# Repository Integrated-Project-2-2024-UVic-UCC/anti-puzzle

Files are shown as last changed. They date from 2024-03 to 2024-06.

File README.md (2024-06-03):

<div align="center">
<h1 align="center">ANTI-PUZZLE 🧩</h1>
</div>
<div align="center">

IMAGE ALT TEXT HERE (https://www.youtube.com/watch?v=cqxajy784bM)

</div>

<p><strong>Forget conventional puzzles❗</strong> Anti-Puzzle offers a unique and engaging challenge designed specifically for elderly.🤶 It goes beyond traditional puzzles, aiming to improve reflexes, decision-making skills, and hand-eye coordination, all while keeping things fun and interactive. </p>

<p><strong>How does it work❓</strong> Instead of fitting pieces together, the goal is to strategically position a piece to prevent it from escaping. This fast-paced and engaging gameplay keeps players on their toes, sharpening their mental agility and reaction time.🫳🎮 </p>

## About the project

- 🔁 Bidirectional Movement CoreXY  
- 📲 People Interaction
- 🧲 Magnetic Detection for the Repulsion
- 💪 Different Levels in function of Capabilities

<br>

## Project *review*
<div align="center">
<table>
<tr>
<td width="100%">
<h3 align="center">Anti-Puzzle BOM 📖✔️</h3>
<div align="center">
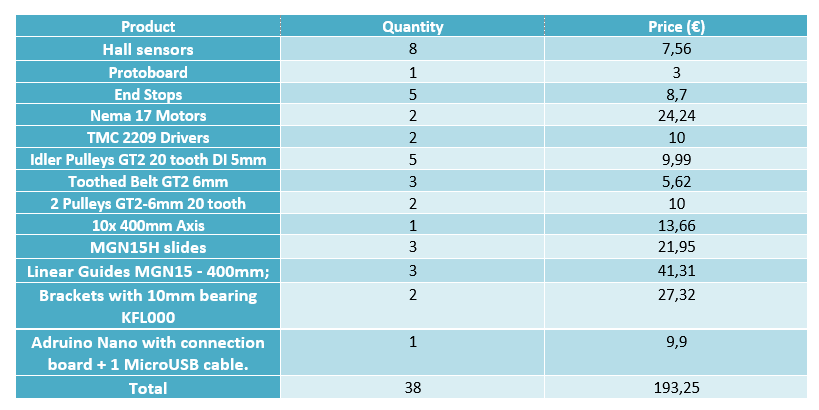
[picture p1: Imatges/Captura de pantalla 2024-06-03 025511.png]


<p>In this section you will see each of the components that will shape this project. For each component you will have a purchase link.💲 </p>
</div>
                                                                                      
</td>

<table>
<tr>
<td width="50%">
<h3 align="center">Mechanical Part ⚙️</h3>
<div align="center">
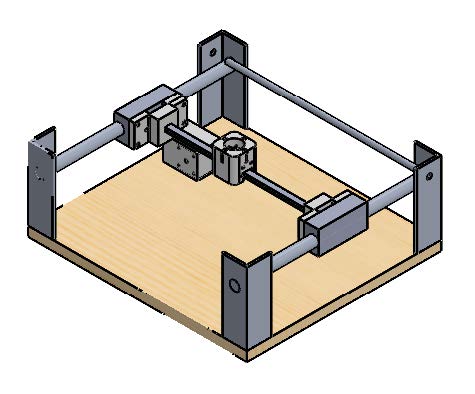
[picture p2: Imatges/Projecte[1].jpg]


<p>In this section you will be able to have blueprints and printable files as well as the original files of each one of the pieces.</p>
</div>
                                                                                      
</td>       

<td width="50%">
<h3 align="center">Electrical Part ⚡</h3>
<div align="center">
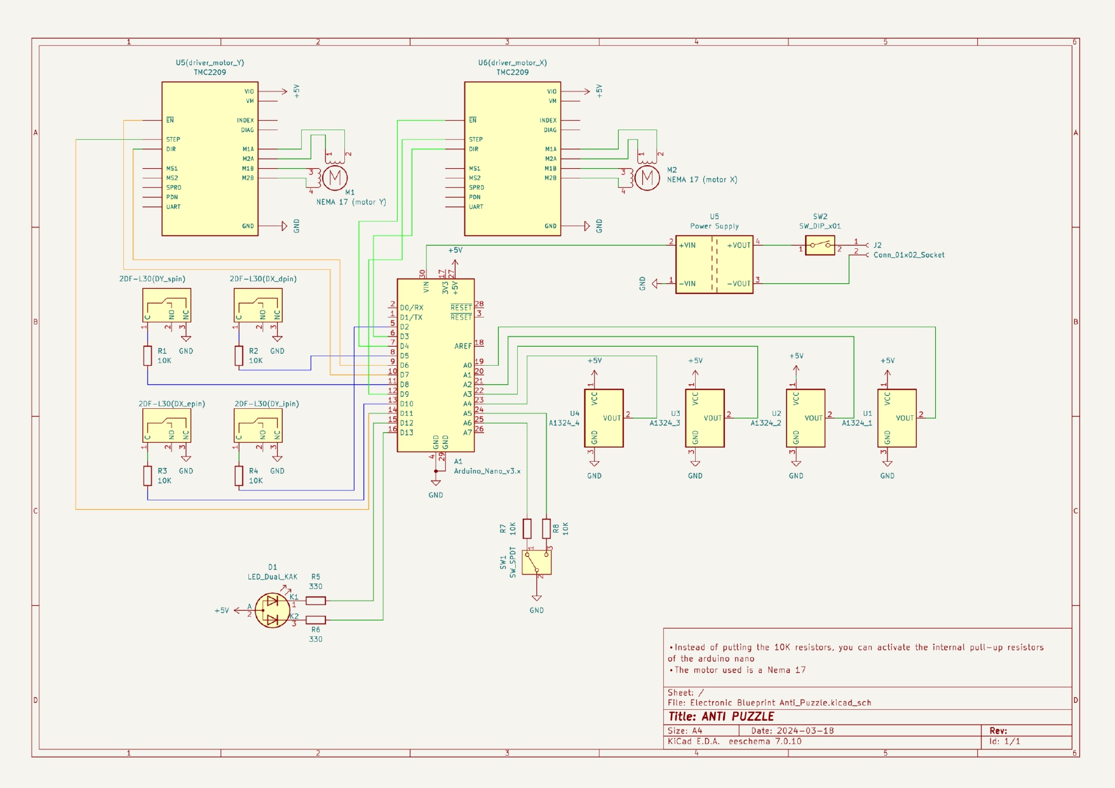
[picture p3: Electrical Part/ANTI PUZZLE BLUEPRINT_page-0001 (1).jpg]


<p>In this section you will be able to see the drawings and the electronic designs as well as the datasheets.</p>
</div>
                                                                                      
</td>  
</table>                                                                                 
</div>
<br>

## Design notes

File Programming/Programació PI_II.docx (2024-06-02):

Especificaciones del Motor NEMA 17HS8401

1. Torque: Hasta 0.4 Nm (holding torque)
2. Velocidad: Máxima de 1000-1200 RPM dependiendo del voltaje y driver
3. Corriente nominal: Aproximadamente 1.7 A por fase
4. Tamaño: Compacto, adecuado para aplicaciones de bajo espacio

Análisis de los Cálculos

En el documento proporcionado, se detallan los siguientes resultados clave:

1. Torque requerido:
  - Torque total requerido (T): 0.1746 Nm
  - Torque de aceleración (Ta): 0.00032948 Nm
  - Torque de carga (TL): 0.1160 Nm
2. Velocidad requerida:
  - Velocidad de operación (Vm1): 954.9 RPM

Comparación con las Especificaciones del Motor

1. Torque: El motor NEMA 17HS8401 proporciona un torque de hasta 0.4 Nm, lo cual es más que suficiente para cubrir el torque total requerido de 0.1746 Nm. Esto incluye el torque de carga y el de aceleración, más un factor de seguridad de 1.5.
2. Velocidad: El motor NEMA 17HS8401 puede operar a velocidades de hasta 1200 RPM, lo cual es adecuado dado que la velocidad requerida es de aproximadamente 954.9 RPM.

Justificación

- Capacidad de Torque: El motor tiene una capacidad de torque que es más del doble del requerido (0.4 Nm frente a 0.1746 Nm), lo que asegura que pueda manejar la carga sin sobrecarga y proporciona un margen de seguridad adecuado.
- Velocidad de Operación: La velocidad de operación del motor (hasta 1200 RPM) excede ligeramente la velocidad requerida de 954.9 RPM, asegurando que pueda cumplir con las necesidades de operación incluso en condiciones variables.
- Factores de Seguridad: El análisis incluye un factor de seguridad de 1.5, lo cual es considerado adecuado para la mayoría de aplicaciones industriales y asegura una operación confiable del sistema.

El motor NEMA 17HS8401 es una elección óptima para la aplicación debido a su capacidad para manejar el torque y la velocidad requeridos, así como a su tamaño compacto y eficiencia. Los cálculos muestran que el motor puede manejar la carga con un margen adecuado de seguridad, garantizando así un rendimiento confiable y eficiente.

Justificación del Uso de un Solo Imán Grande en Lugar de Múltiples Imanes Pequeños

Contexto de la Decisión

En el proyecto, se decidió utilizar un solo imán grande en lugar de múltiples imanes pequeños para cumplir con los requisitos operativos y de rendimiento. La elección se centró en asegurar una fuerza de sujeción adecuada y mantener la precisión del sistema para un rendimiento óptimo durante el uso.

Detalles del Imán Seleccionado

El imán seleccionado es un imán de samario disco Ø 25x5 mm niquelado (Referencia: SD-25-05-NI), cuyas especificaciones técnicas son:

- Material: Samario
- Forma: Disco
- Dimensiones: 25 mm de diámetro y 5 mm de alto
- Fuerza de sujeción: 4,90 kg aproximadamente
- Temperatura máxima de servicio: 300 ºC
- Remanencia: 1.03-1.08 T
- Peso: 20 g

Razones para Elegir un Solo Imán Grande

1. Fuerza de Sujeción:
  - Imanes Pequeños: Requerirían varios imanes pequeños para alcanzar la misma fuerza de sujeción que un imán grande. La distribución de fuerza podría no ser uniforme, lo que puede llevar a puntos de sujeción ineficaces y posibles fallos en el sistema.
  - Imán Grande: Proporciona una fuerza de sujeción concentrada de 4,90 kg, asegurando una sujeción más robusta y uniforme.
2. Precisión Mejorada:
  - Imanes Pequeños: La colocación de varios imanes pequeños puede llevar a desalineaciones y variaciones en la fuerza de sujeción, afectando la precisión del sistema.
  - Imán Grande: Un solo imán grande garantiza una mayor precisión en la sujeción y posicionamiento, manteniendo el rendimiento del sistema conforme a las expectativas de precisión establecidas.
3. Facilidad de Instalación y Mantenimiento:
  - Imanes Pequeños: Instalar múltiples imanes pequeños requiere más tiempo y esfuerzo, y el riesgo de perder algunos durante la instalación o el mantenimiento es mayor.
  - Imán Grande: Simplifica el proceso de instalación y reduce la complejidad del mantenimiento, ya que solo se maneja un componente en lugar de muchos.
4. Durabilidad y Resistencia a Altas Temperaturas:
  - Imán Grande: El imán de samario elegido tiene una temperatura máxima de servicio de 300 ºC y una temperatura de Curie de 800 ºC, lo que asegura su durabilidad en condiciones extremas.
  - Imanes Pequeños: Pueden tener variaciones en sus propiedades térmicas, lo que podría llevar a inconsistencias en su comportamiento bajo temperaturas elevadas.

La decisión de utilizar un solo imán grande en lugar de múltiples imanes pequeños se basa en la necesidad de garantizar una fuerza de sujeción adecuada, mejorar la precisión del sistema y simplificar tanto la instalación como el mantenimiento. Estas ventajas aseguran que el sistema funcione de acuerdo con las expectativas y requisitos del proyecto, proporcionando un rendimiento confiable y consistente.

Descripción del Diagrama de Flujo

1. Inicio

- Inicialización de los pines: Configura los pines de entrada/salida del microcontrolador.
- Configuración de los timers: Establece los temporizadores necesarios para controlar la operación de los motores y otras funciones de temporización.
- Ciclo Home: Inicia el proceso de homing, que mueve los motores a una posición inicial de referencia.

2. Ciclo Home

- Movimiento del motor X: Activa el motor X hasta que toca el detector lx, indicando la posición inicial del eje X.
- Movimiento del motor Y: Activa el motor Y hasta que toca el detector ly, indicando la posición inicial del eje Y.
- Centro: Calcula la posición central del área de trabajo, basado en los límites detectados.
- Final posición Home: Finaliza el proceso de homing y prepara el sistema para la operación.

3. Selección de Nivel (Botón Niveles)

- El usuario selecciona uno de los tres niveles:
  - Nivel 1 (Atracción): La máquina simula el efecto de atracción entre imanes.
  - Nivel 2 (Repulsión): La máquina simula el efecto de repulsión entre imanes.
  - Nivel 3 (Imposible): La máquina salta a posiciones aleatorias, haciendo que el usuario necesite ser muy preciso y exacto.

4. Operación en los Niveles

- Dependiendo del nivel seleccionado, la máquina ejecuta diferentes comportamientos:
  - Nivel 1: Activa patrones de movimiento que simulan la atracción magnética.
  - Nivel 2: Activa patrones de movimiento que simulan la repulsión magnética.
  - Nivel 3: Activa movimientos aleatorios para desafiar al usuario.
- Tras completar la operación en el nivel seleccionado, el sistema vuelve al estado de Home.

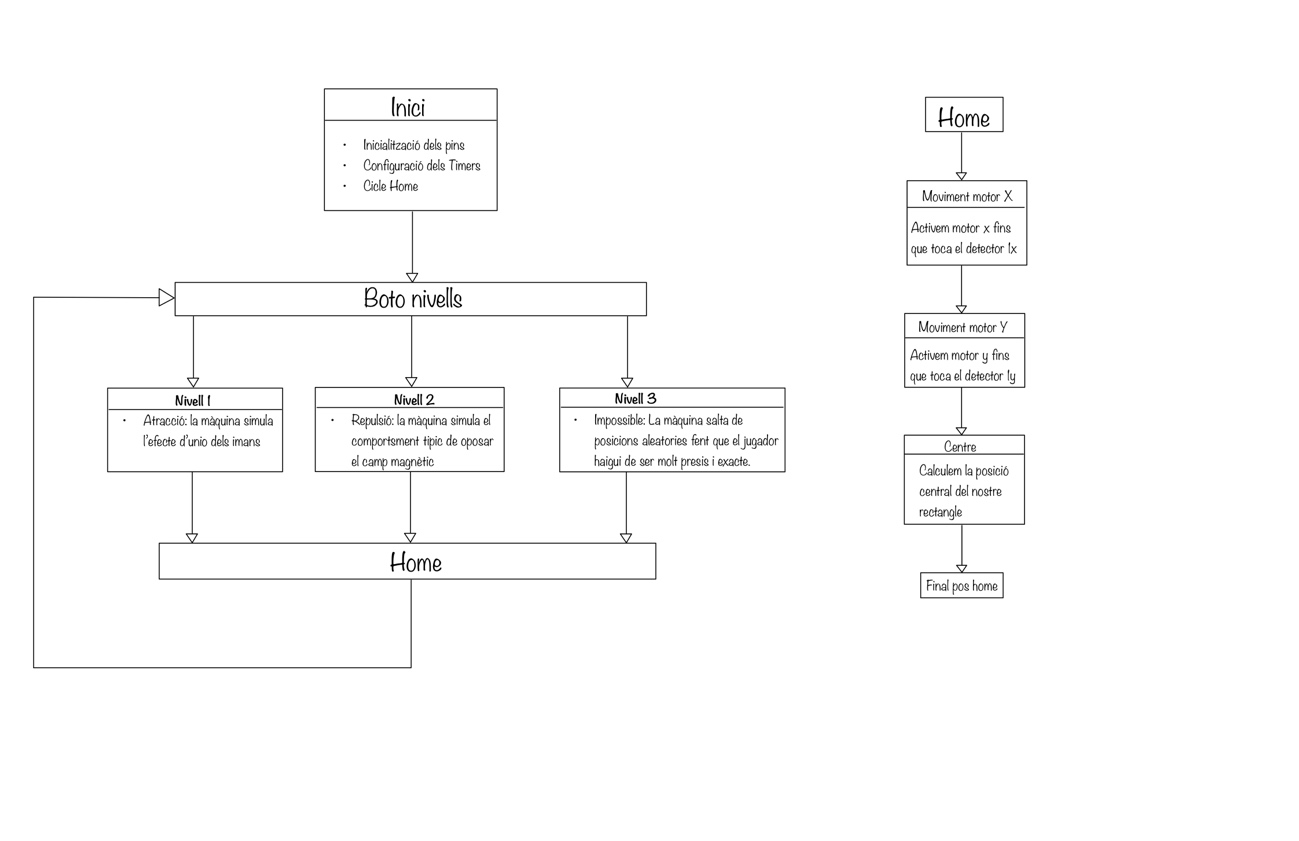
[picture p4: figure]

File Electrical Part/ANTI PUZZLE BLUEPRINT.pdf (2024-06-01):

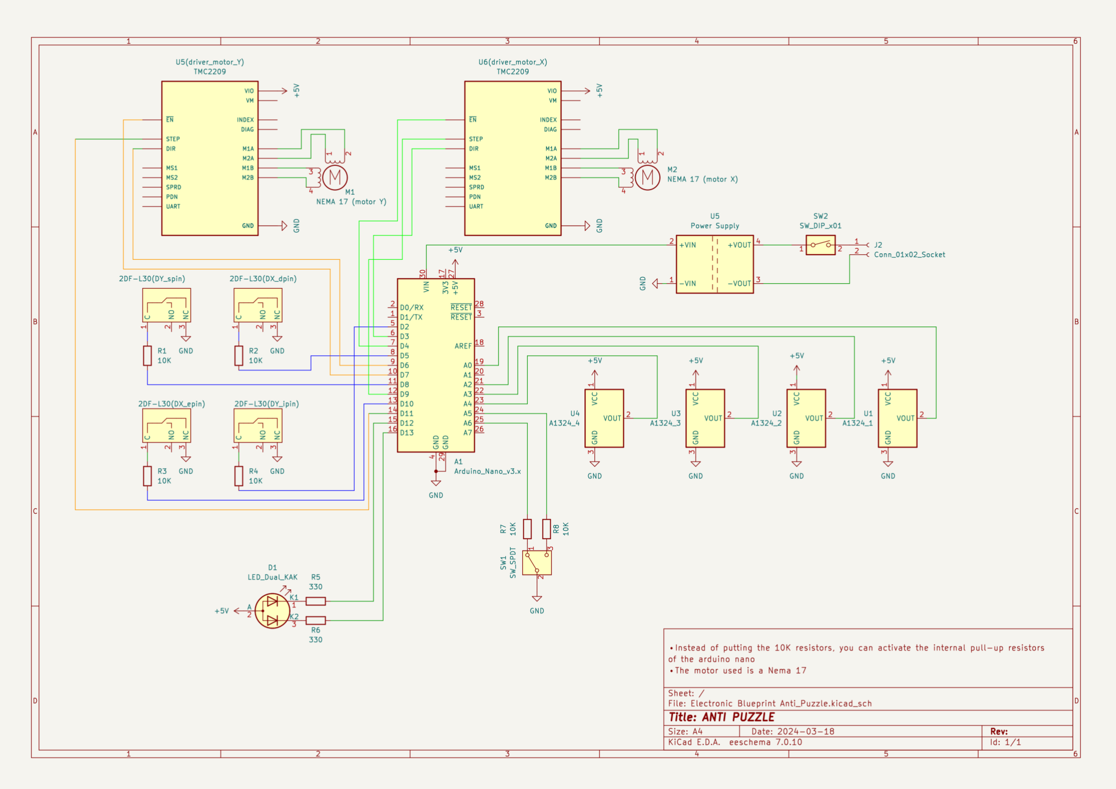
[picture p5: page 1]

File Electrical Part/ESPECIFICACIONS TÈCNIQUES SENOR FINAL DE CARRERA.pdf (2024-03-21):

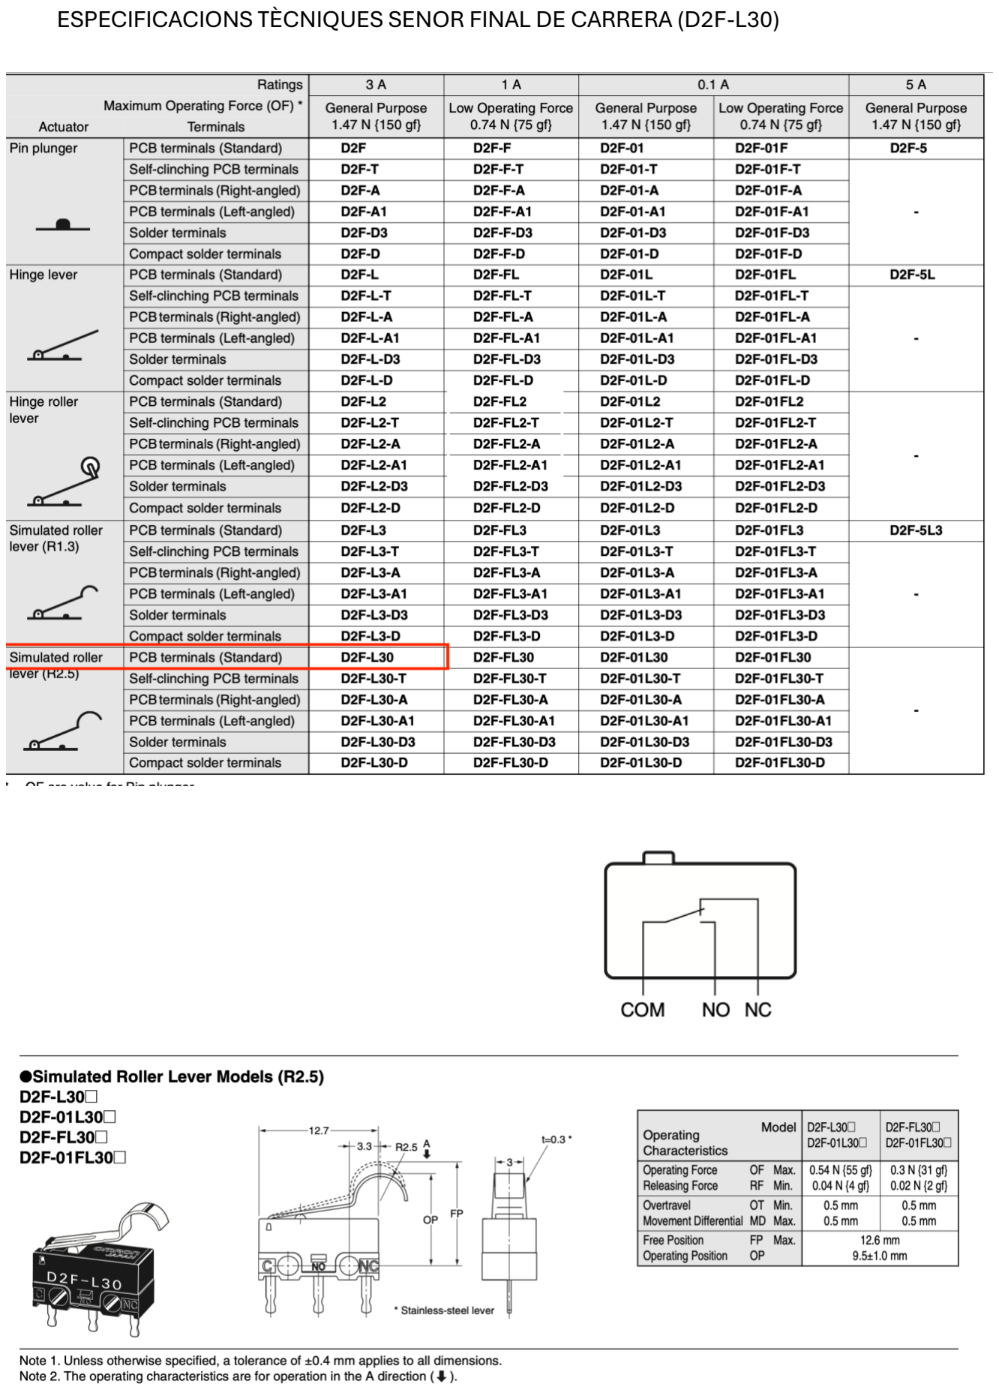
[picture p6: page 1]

ESPECIFICACIONS TÈCNIQUES SENOR FINAL DE CARRERA (D2F-L30)

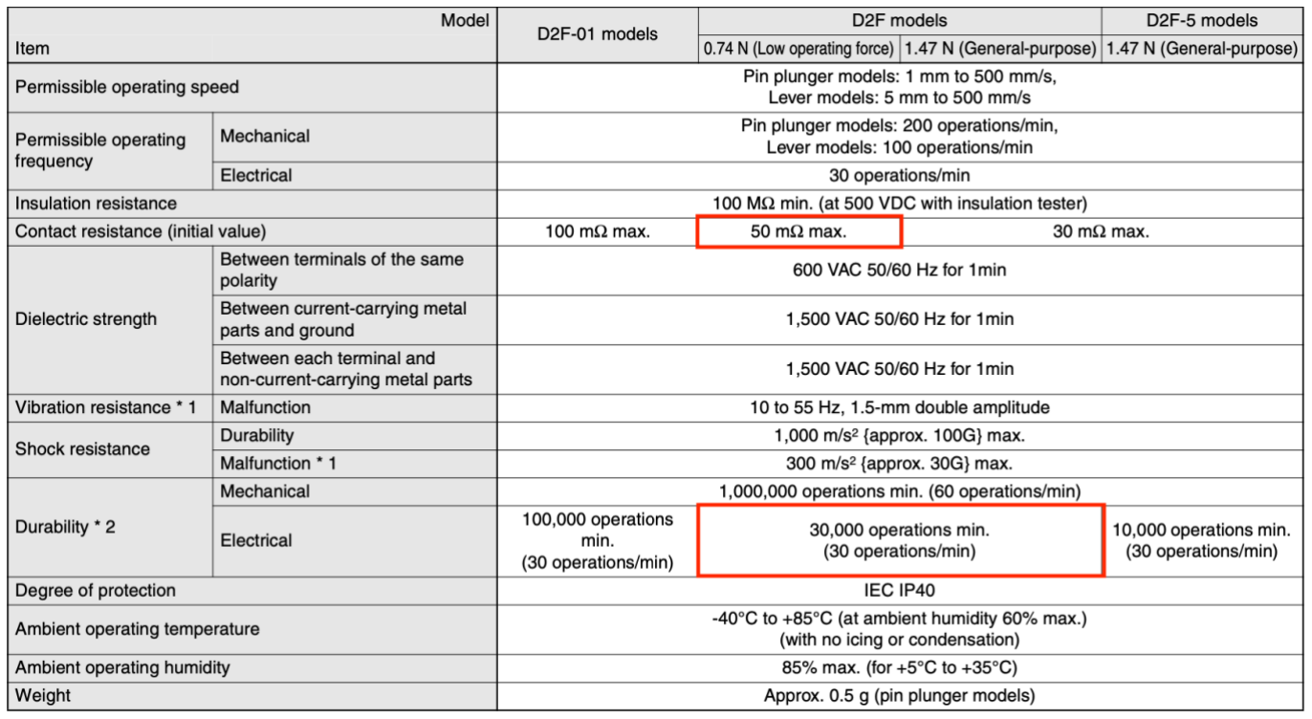
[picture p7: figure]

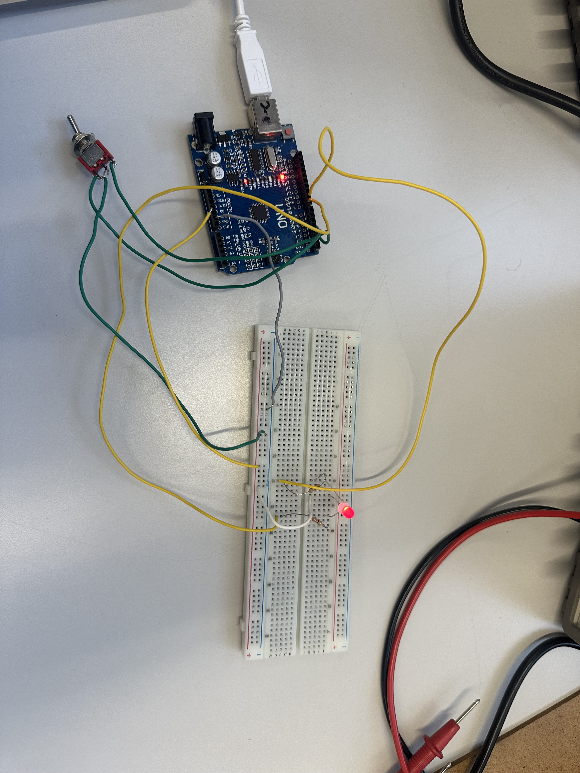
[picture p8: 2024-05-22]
Programming/foto interrputor.jpeg

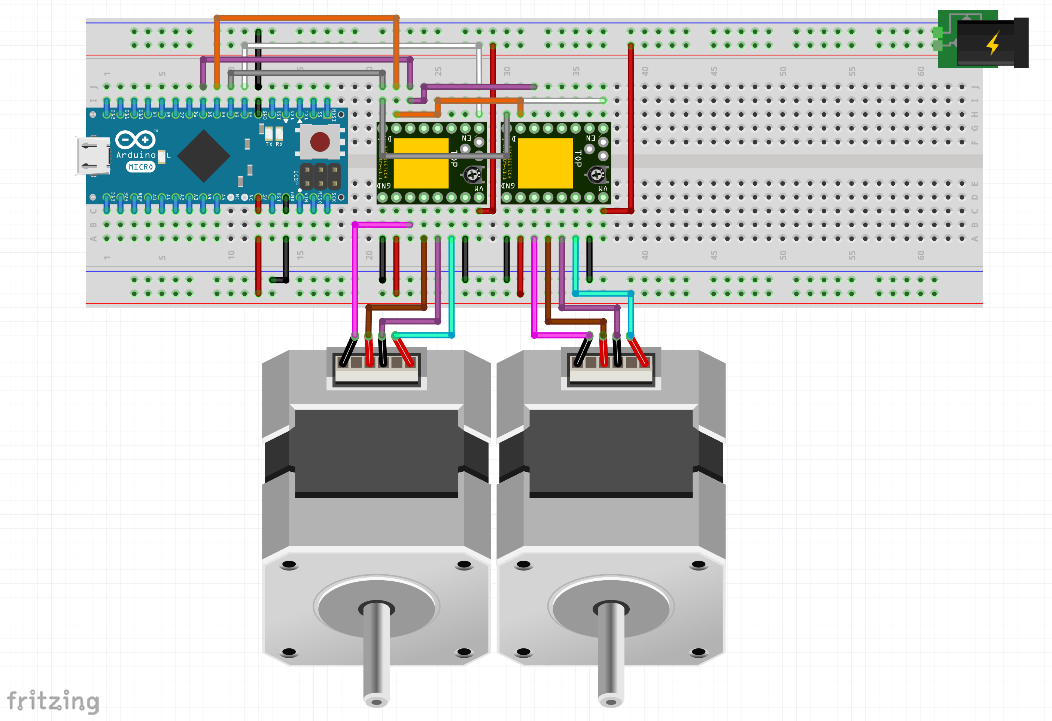
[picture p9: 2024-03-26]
Programming/Motor HW/HW diagram.png

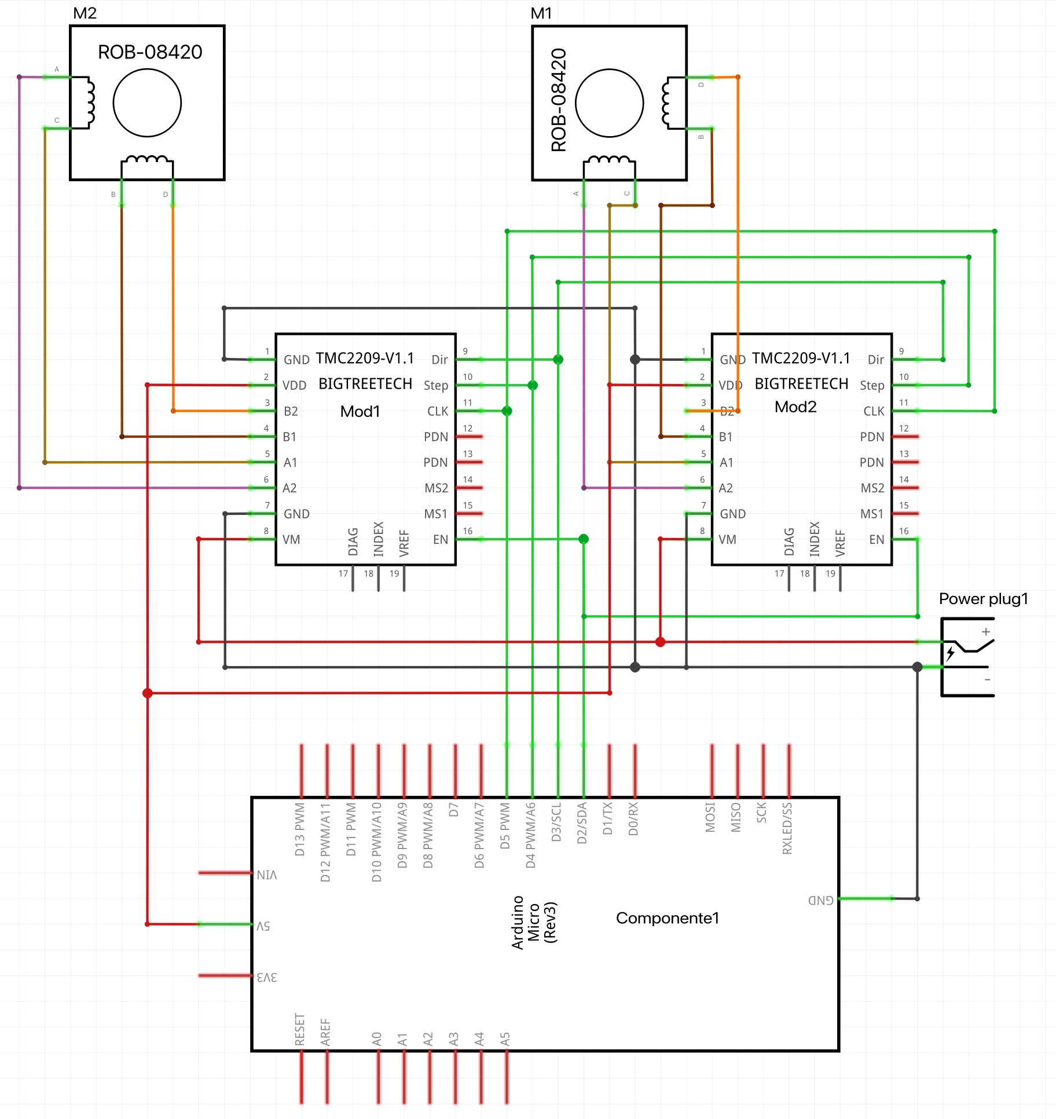
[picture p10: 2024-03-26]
Programming/Motor HW/Motor Controller.png

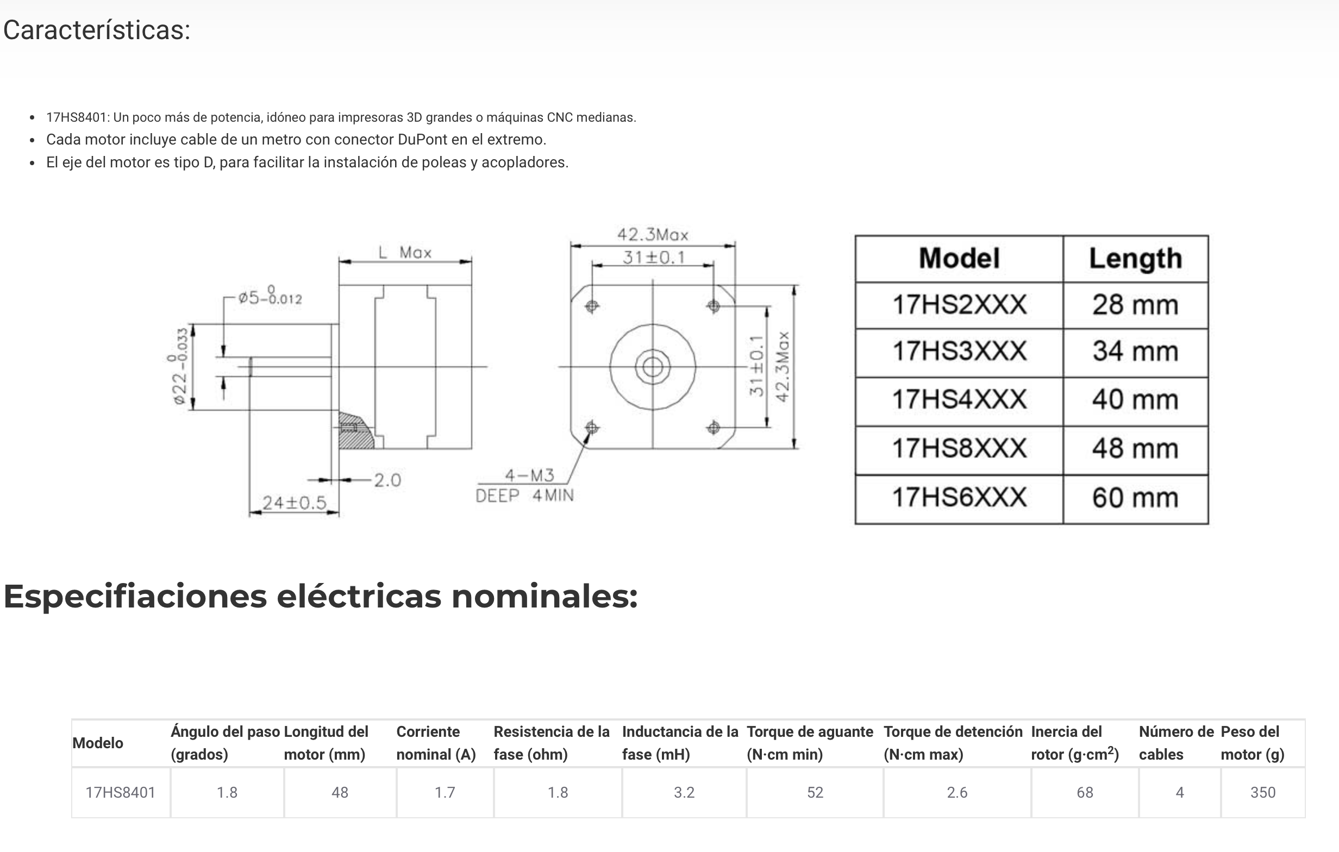
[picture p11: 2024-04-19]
Programming/Motor HW/Captura de pantalla 2024-04-16 a las 17.24.59.png

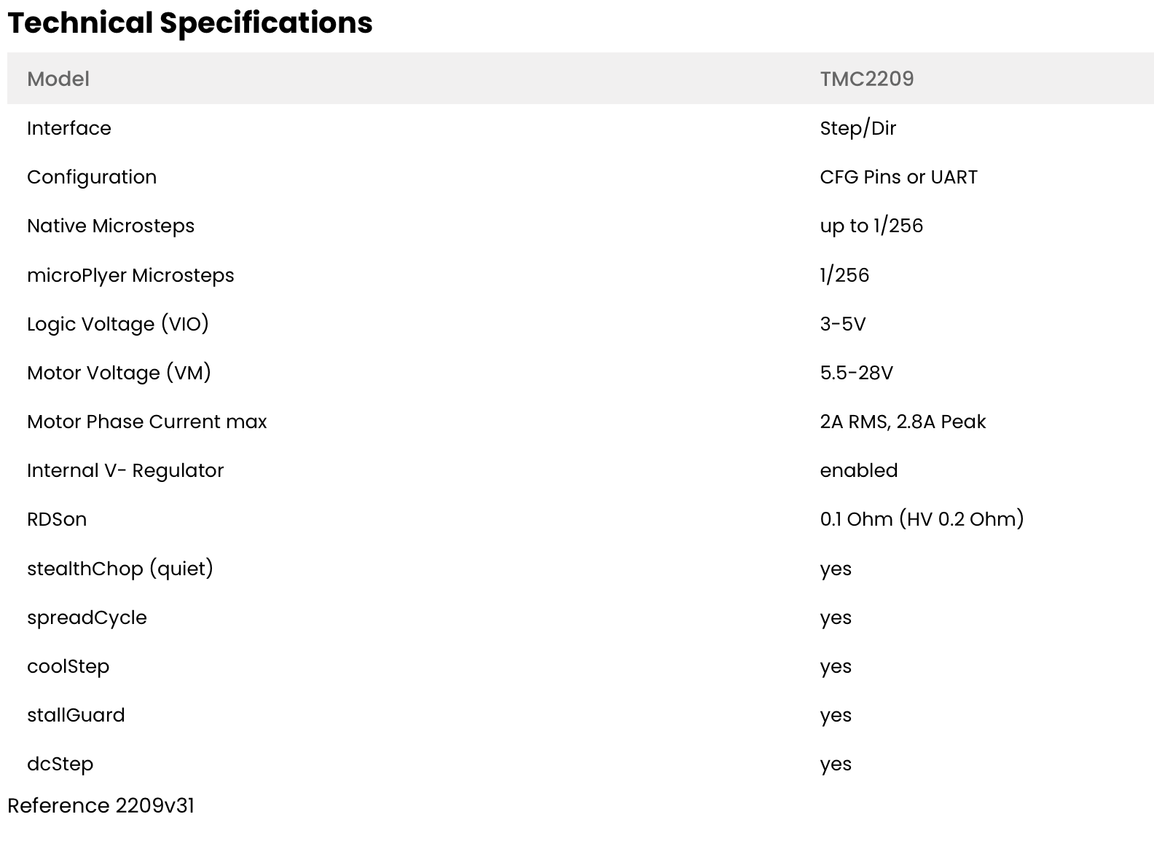
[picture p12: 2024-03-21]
Electrical Part/Especificacions tècniques TMC 2209.png

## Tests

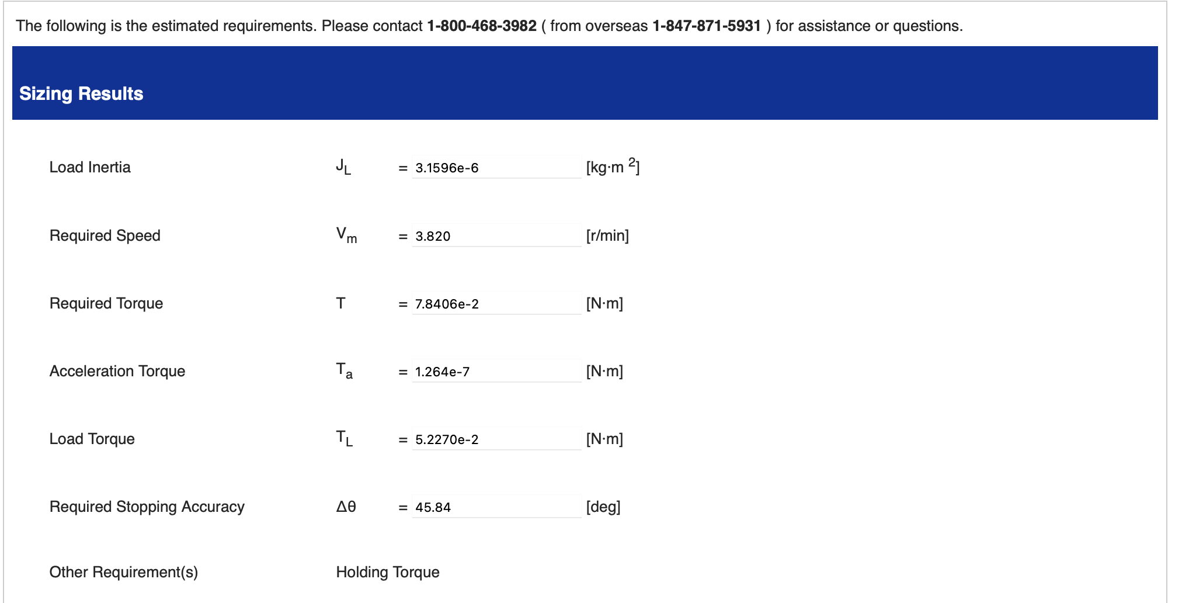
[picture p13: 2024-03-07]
Programming/Calculations motor/Force result.png

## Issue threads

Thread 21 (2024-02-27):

Short Magnet reaction implementation code

CarlesNV11, 2024-02-27:

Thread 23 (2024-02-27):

Short motors movement code

CarlesNV11, 2024-02-27:

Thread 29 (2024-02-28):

Calculate Axis Forces

CarlesNV11, 2024-02-28:

RRoura, 2024-03-01:
i can't find the intrinsic resistance of our sliding block and i will use this instead, because it has to be more or less the same.

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

RRoura, 2024-03-01:
sliding block propulsion force

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

RRoura, 2024-03-05:
And the propulsion force of the Y axis is the same of the sliding block but changing the W, we have to sum the W of the other pieces that moves in the Y axis.

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

Closed 2024-03-17.

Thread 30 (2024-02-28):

Study Core-XY Movement

CarlesNV11, 2024-02-28:

RRoura, 2024-03-02:
CoreXY is a kinematic system used in 3D printers to control the movement of the print head (extruder) in the X and Y axes. It provides a precise and efficient way to move the print head across the print bed. The CoreXY system is known for its speed, accuracy, and ability to minimize vibrations. Here's how the CoreXY movement works:

**Belt Arrangement:**

CoreXY printers use two stepper motors, one for each axis (X and Y).
Belts are attached to the print head, and they run through a system of pulleys and idlers.

**Belt Crossings:**

The belts cross each other at some point in the printer's frame. This crossing is typically at a 45-degree angle.
This crossing allows for the coordinated movement of both motors to control the position of the print head in both the X and Y directions.

**Motor Control:**

The two motors work together to control the position of the print head. When both motors move in the same direction, the print head moves along one axis (X or Y).
When the motors move in opposite directions, the print head moves along a diagonal path, allowing for movement in both the X and Y directions simultaneously.

**Reduced Inertia:**

One of the advantages of the CoreXY system is reduced moving mass. Since the motors only need to move the print head and not the bed, the moving mass is lighter, resulting in faster and more precise movements.

**High-Speed Printing:**

The CoreXY system is well-suited for high-speed printing due to its ability to quickly and accurately position the print head.

**Accuracy and Precision:**

The CoreXY system minimizes backlash and ensures precise control over the movement of the print head, contributing to the overall print quality.

**Parallelism:**

The belts in a CoreXY system are usually kept parallel, which helps in maintaining accuracy and avoiding racking issues.

In summary, CoreXY provides a reliable and efficient mechanism for moving the print head in 3D printers, enabling faster and more accurate printing. Its design principles make it popular in various 3D printer models.

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

Closed 2024-03-17.

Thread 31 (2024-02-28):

Study 3D Printing Tolerances

CarlesNV11, 2024-02-28:

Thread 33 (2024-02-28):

Design Piece

CarlesNV11, 2024-02-28:

RRoura, 2024-04-10:
The piece design has been carefully considered with regard to the magnet we'll use, as well as the player's comfort when gripping and playing with it.

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

Closed 2024-04-10.

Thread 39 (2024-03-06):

Redisign Structure

CarlesNV11, 2024-03-06:

RRoura, 2024-03-17:
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

The structural layout has undergone a redesign aimed at optimizing the overall user experience. One significant modification involves raising the base of the piece, a strategic adjustment intended to eliminate any potential hindrances that might impede the fluid movement of both the game elements and the user interacting with the system.

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

Additionally, in accordance with the provided instructions, we have successfully integrated a dedicated system designed to facilitate the tensioning of the belts, ensuring optimal performance and reliability of the mechanism.

RRoura, 2024-03-17:
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

This would be the final prototype.

Closed 2024-03-17.

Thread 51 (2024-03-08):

List of material received

moises-garin, 2024-03-08:
This is the list of the materials you have received. Each item will be checked-out once returned at the end of the course. All material must be returned before receiving your final maks.

**IMPORTANT** Ony the teachers must modify this issue. In case of detecting an error, you must inform the teachers inmediately.

- [ ] 4 Sensors Hall
- [ ] 1 protoboard

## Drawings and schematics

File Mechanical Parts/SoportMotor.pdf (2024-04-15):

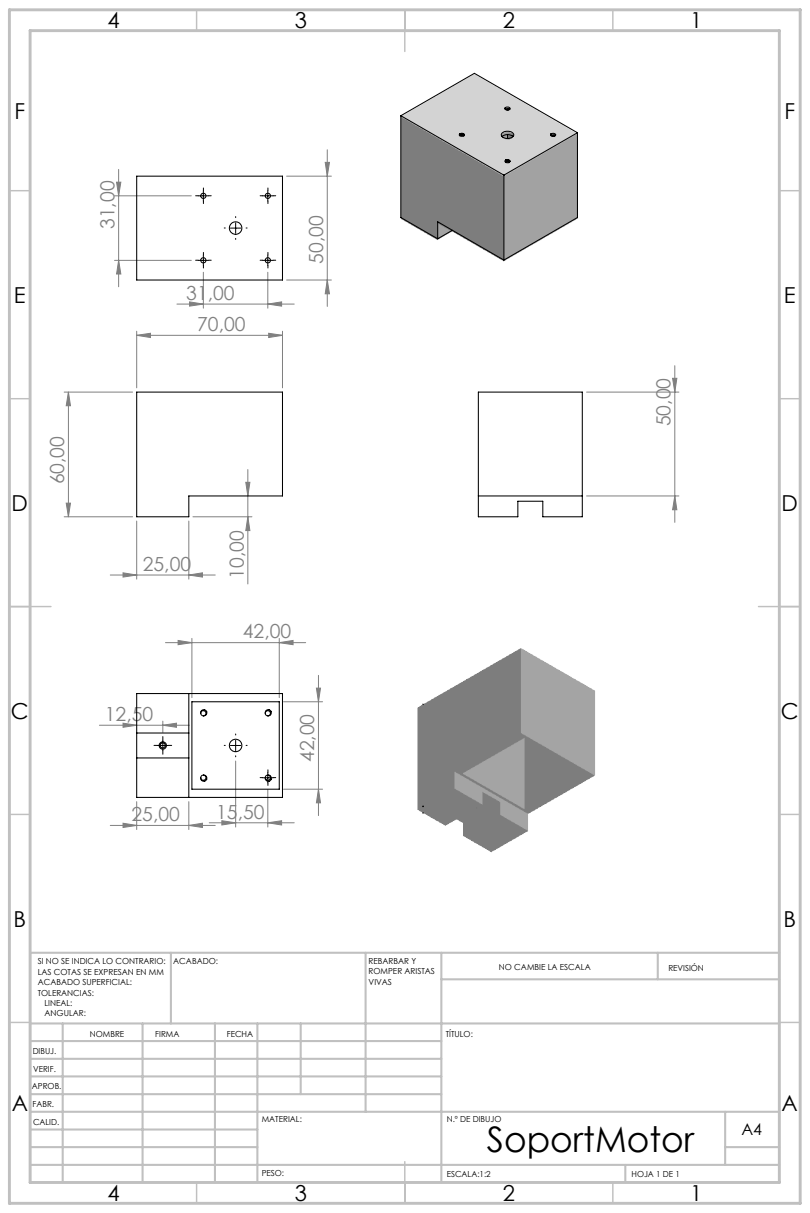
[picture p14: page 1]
ACABADO:; REBARBAR Y; ROMPER ARISTAS; NO CAMBIE LA ESCALA; REVISIÓN; ESCALA:1:2; HOJA 1 DE 1

SI NO SE INDICA LO CONTRARIO:
LAS COTAS SE EXPRESAN EN MM
ACABADO SUPERFICIAL:
TOLERANCIAS:
LINEAL:
ANGULAR:

NOMBRE | FIRMA | FECHA | | | | TÍTULO:

DIBUJ.
VERIF.
APROB.
FABR.
CALID. | | | | MATERIAL: | N.º DE DIBUJO SoportMotor | A4

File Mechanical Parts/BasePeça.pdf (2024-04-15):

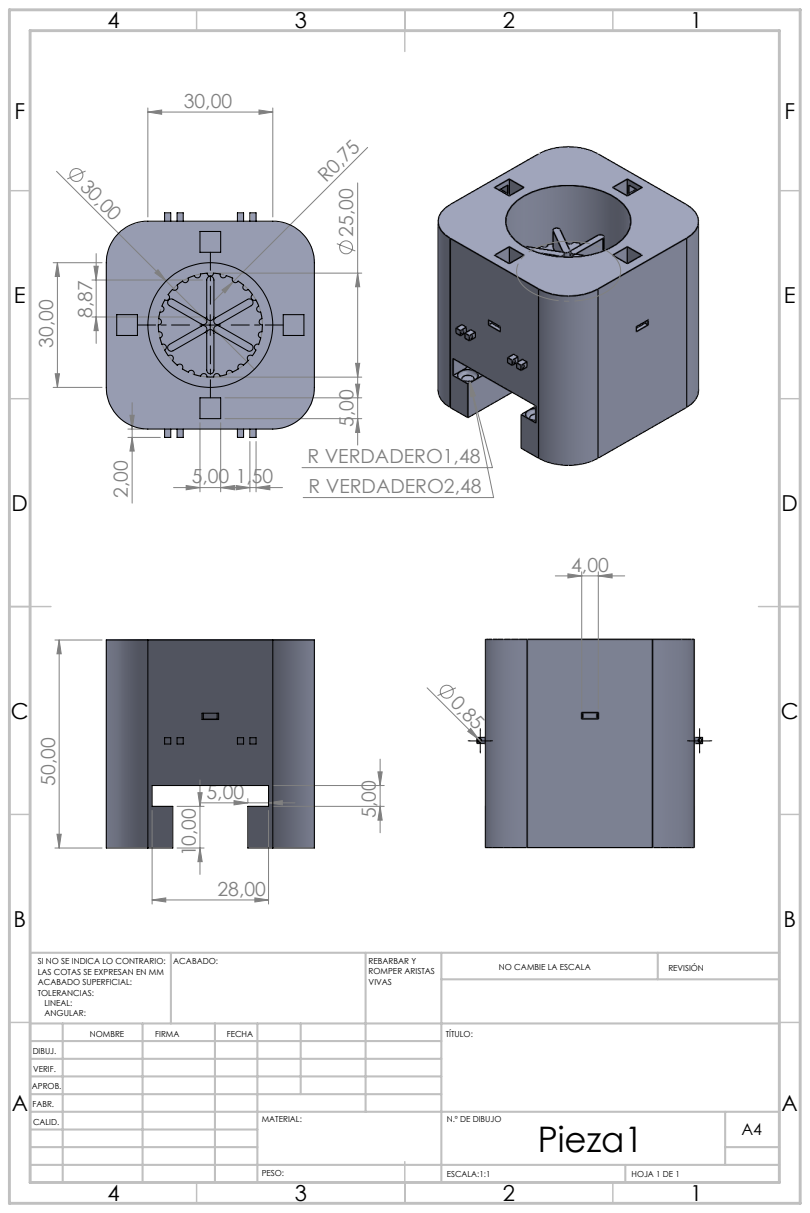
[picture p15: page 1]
R VERDADERO2,48; R VERDADERO1,48; ACABADO:; REBARBAR Y; ROMPER ARISTAS; NO CAMBIE LA ESCALA; REVISIÓN; ESCALA:1:1; HOJA 1 DE 1

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

NOMBRE | FIRMA | FECHA | | | | TÍTULO:

DIBUJ.
VERIF.
APROB.
FABR.
CALID. | | | | MATERIAL: | N.º DE DIBUJO Pieza1 | A4

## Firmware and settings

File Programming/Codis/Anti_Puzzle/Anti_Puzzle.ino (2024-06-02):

#include <util/atomic.h>
#include <EEPROM.h>

 /*
 __________________
/                  \  A0 = sensor inferior dret
|  s4          s2  |  A4 = senso inferior esquerre
|                  |  A3 = sensor superior dret
|                  |  A2 = sensor superior esquerre
|  s3          s1  |
\__________________/
*/

// Pins motor X
#define X_STEP_PIN 9
#define X_DIR_PIN 3
#define X_ENABLE_PIN 4

// Pins motor Y
#define Y_STEP_PIN 11
#define Y_DIR_PIN 6
#define Y_ENABLE_PIN 7

#define DX_epin 10 // Nuevo detector de final de carrera en el eje X
#define DY_spin 8  // Nuevo detector de final de carrera en el eje Y
#define DX_dpin 5 // Nuevo detector de final de carrera en el eje X
#define DY_ipin 2 // Nuevo detector de final de carrera en el eje Y

const int pinLED_Rojo = 8;    // Pin para el LED rojo
const int pinLED_Verde = 9;    // Pin para el LED verde
const int pinInterruptor1 = 2; // Pin para el primer contacto del interruptor (posición 1)
const int pinInterruptor2 = 3; // Pin para el segundo contacto del interruptor (posición 3)

float A1324_1 = A0; 
float A1324_2 = A1;
float A1324_3 = A2;
float A1324_4 = A3;

volatile long totalStepsX, totalStepsY; 

bool dirX;
bool dirY;

// ················································
// Timers i preescales
// ················································

unsigned int Preescaler(unsigned int frecuenciaDeseada){
  unsigned long frecuenciaReloj = 16000000UL; // Frecuencia del reloj del ATmega328P en Hz
  unsigned long contadorMaximo =  65535UL; // Contador máximo para los timers de 16 bits
  
  unsigned int preescaler = frecuenciaReloj / ((frecuenciaDeseada) * contadorMaximo * 2) - 1;
  unsigned long frecuenciaTimer1 = frecuenciaReloj / preescaler;

  return frecuenciaTimer1;
}

void configurarTimer1(unsigned int frecuenciaDeseada) {

  TCCR1A = 0; 
  TCCR1B = 0;
  TCNT1  = 0; 

  OCR1A = Preescaler(frecuenciaDeseada);
  // Utilitzem un preescaler de 8 bits perque ens permet mes control en freq altes i per tant ens permet mes velocitat 
  TCCR1A |= (1 << COM1A0); 
  TCCR1B |= (1 << WGM12); 
  TCCR1B |= (0 << CS12); 
  TCCR1B |= (1 << CS11); 
  TCCR1B |= (1 << CS10); 
  TIMSK1 |= (1 << OCIE1A); 
}

void configurarTimer2(unsigned int frecuenciaDeseada) {

  TCCR2A = 0; // Configuración inicial de los registros
  TCCR2B = 0;
  TCNT2  = 0; // Inicializamos el contador del timer 2

  OCR2A = Preescaler(frecuenciaDeseada); // Configuramos el preescaler

  TCCR2A |= (1 << COM2A0); // Configuramos el Timer 2 para el modo CTC (Clear Timer on Compare Match) y activamos la salida OC2A
  TCCR2A |= (1 << WGM21); // Configuramos el Timer 2 para el modo CTC
  TCCR2B |= (0 << CS20);
  TCCR2B |= (0 << CS21); // Configuramos el prescaler para que el timer cuente a la frecuencia del reloj
  TCCR2B |= (1 << CS22);
  TIMSK2 |= (1 << OCIE2A); // Habilitamos la interrupción de comparación del Timer 2
}

// ················································
// Habilita i deshabilita motors
// ················································

bool enableMotorX() {
  digitalWrite(X_ENABLE_PIN, LOW);
} 

bool disableMotorX() {
  digitalWrite(X_ENABLE_PIN, HIGH);
} 

bool enableMotorY() {
  digitalWrite(Y_ENABLE_PIN, LOW);
} 

bool disableMotorY() {
  digitalWrite(Y_ENABLE_PIN, HIGH);
} 

// ################################################
// Geters
// ################################################

bool getDX_d(){
  bool DX_d = digitalRead(DX_dpin); // Cambio el pin al detector nuevo
  return DX_d;
}

bool getDX_e(){
  bool DX_e = digitalRead(DX_epin); // Cambio el pin al detector nuevo
  return DX_e;
}

bool getDY_i(){
  bool DY_i = digitalRead(DY_ipin); // Cambio el pin al detector nuevo
  return DY_i;
}

bool getDY_s(){
  bool DY_s = digitalRead(DY_spin); // Cambio el pin al detector nuevo
  return DY_s;
}

long getStepsX(void){
  long aux;
  ATOMIC_BLOCK(ATOMIC_RESTORESTATE) {
    aux = totalStepsX;
  };
  return aux;
}

long getStepsY(void){
  long aux;
  ATOMIC_BLOCK(ATOMIC_RESTORESTATE) {
    aux = totalStepsY;
  };
  return aux;
}

long getSpeedX(){
  long speedX;
  ATOMIC_BLOCK(ATOMIC_RESTORESTATE) {
    speedX = OCR1A;
  };
  return speedX;
}

long getSpeedY(){
  long speedY; 
  ATOMIC_BLOCK(ATOMIC_RESTORESTATE) {
    speedY = OCR2A;
  };
  return speedY;
}

// ################################################
// Seters 
// ################################################

void setDirectionMotorX(bool dir){
  dirX = dir;
  digitalWrite(X_DIR_PIN, dirX);
}

void setDirectionMotorY(bool dir){
  dirY = dir;
  digitalWrite(Y_DIR_PIN, dirY);
}

void setSpeedMotorX(float speed){
  OCR1A = speed;
  TCNT1 = 0;
}

void setSpeedMotorY(float speed){
  OCR2A = speed;
  TCNT2 = 0;
} 

// =================================================
// Colors LED
// =================================================

void encenderVerde() {
  digitalWrite(pinLED_Rojo, HIGH);   // Apagar LED rojo
  digitalWrite(pinLED_Verde, LOW); // Encender LED verde
}

void encenderNaranja() {
  digitalWrite(pinLED_Rojo, LOW);  // Encender LED rojo
  digitalWrite(pinLED_Verde, LOW); // Encender LED verde 
}

void encenderRojo() {
  digitalWrite(pinLED_Rojo, LOW);  // Encender LED rojo
  digitalWrite(pinLED_Verde, HIGH);  // Apagar LED verde
}

// @@@@@@@@@@@@@@@@@@@@@@@@@@@@@@@@@@@@@@@@@@@@@@@@
// Programa  ---  CI. ---  HOME. ----  Nivells.  
// @@@@@@@@@@@@@@@@@@@@@@@@@@@@@@@@@@@@@@@@@@@@@@@@

void CI() {
  // Paso 1: Mover los motores a la mitad de las coordenadas
  int mitadX = (15300)/2; // Mitad de la coordenada Y que son 15300 micropasos
  int mitadY = (8200)/2; // Mitad de la coordenada X que son 8200 micropasos --> 3200

  int Vx = mitadY / 75;
  int Vy = mitadX / 75;

  setDirectionMotorX(true);
  setDirectionMotorY(true);
  
  setSpeedMotorX(Vx);
  setSpeedMotorY(Vy);

  enableMotorX();
  enableMotorY();

  while ((getStepsY() < mitadY) && (getStepsX() < mitadX)) {}

  disableMotorX();
  disableMotorY();

  // Paso 2: Mover el motor X hacia la derecha para completar los 210mm
  // Calcular los pasos necesarios para recorrer los 210mm en X
  int pasX = getStepsX() + mitadX;
  enableMotorX();
  while ((getStepsX() < pasX)){
    delay(100);
    int difdist = pasX - getStepsX();
    float velocidadX = map(difdist, 0, pasX, 225, 16);
    setSpeedMotorX(velocidadX);
  }
  disableMotorX();
}

void Home() {
  // Paso 1: Mover los motores a la mitad de las coordenadas
  int mitadX = (15300)/2; // Mitad de la coordenada Y que son 15300 micropasos
  int mitadY = (8200)/2; // Mitad de la coordenada X que son 8200 micropasos --> 3200

  int Vx = mitadY / 75;
  int Vy = mitadX / 75;

  // Paso 1: Mover el motor X a la posición de inicio en X
  setDirectionMotorX(false); 
  setDirectionMotorY(false); 

  setSpeedMotorX(150);
  setSpeedMotorY(150);

  enableMotorX();
  
  // Mover motor X
  while (getDX_e()) {
    Serial.println("move");
  } 
  // Serial.println(getDX_d());
  disableMotorX();

  enableMotorY();

  // Mover motor Y
  while (getDY_s()) {}
  // Serial.println(getDY_s());
  disableMotorY();

  totalStepsX = 0;
  totalStepsY = 0;

  MoveToPosition(mitadX,mitadY);
}

void Print(float V1, float V2, float V3, float V4){
  Serial.print(0);
  Serial.print(" ");
  Serial.print(V1);
  Serial.print(" ");
  Serial.print(V2+1000);
  Serial.print(" ");
  Serial.print(V3+2000);
  Serial.print(" ");
  Serial.print(V4+3000);
  Serial.print(" ");
  Serial.print(4000);
  Serial.println(" ");
}

void Nivell_1(){
  int mitadX = 15300 / 2; // Mitad de la coordenada Y que son 15300 micropasos
  int mitadY = 8200 / 2;  // Mitad de la coordenada X que son 8200 micropasos --> 3200
  int stepX = 0;
  int stepY = 0; 

  int val1 = analogRead(A1324_1);
  int val2 = analogRead(A1324_2);
  int val3 = analogRead(A1324_3);
  int val4 = analogRead(A1324_4);

  int eX = CalculerrorX(val1,val2,val3,val4);
  int eY = CalculerrorY(val1,val2,val3,val4);

  // Print(val1, val2, val3, val4);

  int win = val1 + val2 + val3 + val4;

  int sX = 0;
  int sY = 0;
  if (win != 3900) {
    if (eX > 10) {
      sX = -map(abs(eX), 10, 2000, 0, mitadX);
    } else if (eX < -10) {
      sX = -map(abs(eX), -2000, -10, -mitadX, 0);
    }
    if (eY > 10) {
      sY = -map(abs(eY), 10, 2000, 0, mitadY);
    } else if (eY < -10) {
      sY = -map(abs(eY), -2000, -10, -mitadY, 0);
    }
  }

  MoveToPosition(sX, sY);
}

void Nivell_2() {
  int mitadX = 15300 / 2; // Mitad de la coordenada Y que son 15300 micropasos
  int mitadY = 8200 / 2;  // Mitad de la coordenada X que son 8200 micropasos --> 3200
  int stepX = 0;
  int stepY = 0; 

  int val1 = analogRead(A1324_1);
  int val2 = analogRead(A1324_2);
  int val3 = analogRead(A1324_3);
  int val4 = analogRead(A1324_4);

  int eX = CalculerrorX(val1,val2,val3,val4);
  int eY = CalculerrorY(val1,val2,val3,val4);

  int win = val1 + val2 + val3 + val4;

  int sX = 0;
  int sY = 0;

  if (win != 3900) {
    if (eX > 10) {
      sX = map(abs(eX), 10, 2000, 0, mitadX);
    } else if (eX < -10) {
      sX = map(abs(eX), -2000, -10, -mitadX, 0);
    }
    if (eY > 10) {
      sY = map(abs(eY), 10, 2000, 0, mitadY);
    } else if (eY < -10) {
      sY = map(abs(eY), -2000, -10, -mitadY, 0);
    }
  }

  MoveToPosition(sX, sY);
}

void Nivell_3() {
  int mitadX = 15300 / 2; // Mitad de la coordenada Y que son 15300 micropasos
  int mitadY = 8200 / 2;  // Mitad de la coordenada X que son 8200 micropasos --> 3200
  int sX = 0;
  int sY = 0; 

  int val1 = analogRead(A1324_1);
  int val2 = analogRead(A1324_2);
  int val3 = analogRead(A1324_3);
  int val4 = analogRead(A1324_4);

  int eX = CalculerrorX(val1,val2,val3,val4);
  int eY = CalculerrorY(val1,val2,val3,val4);

  int win = val1 + val2 + val3 + val4;

  if (win != 3900) {
    if (abs(eX) > 10 || abs(eY) > 10) {
      sX = random(-mitadX, mitadX);
      sY = random(-mitadY, mitadY);
    }
  }

  MoveToPosition(sX, sY);
}


int CalculerrorX(int hall1,int hall2,int hall3,int hall4){
  int errX = (hall3 + hall4) - (hall2 + hall1);
  return errX;
}

int CalculerrorY(int hall1,int hall2,int hall3,int hall4){
  int errY = (hall2 + hall4) - (hall1 + hall3);
  return errY;
}

void MoveToPosition(long stepX, long stepY) {
  // Serial.print(stepX);
  // Serial.print(" : ");
  // Serial.print(stepX);
  // Serial.println("");

  long errX=10000;
  long errY=10000;
  long periode;

  while(errX>100 || errY>100) {
    delay(100);
    // control eix X
    errX = stepX - totalStepsX;
    setDirectionMotorX(errX>0);

    if (abs(errX)<=100) {
      periode = 255;
    } else if (abs(errX)>3200) {
      periode = 16;
    } else {
      periode = map(abs(errX),100, 3200, 255, 50);
    }
    setSpeedMotorX(periode);

    if (errX>100 && getDX_d() || errX<-100 && getDX_e()) {
      enableMotorX();
    } else {
      disableMotorX();
    }

    // control eix Y
    errY = stepY - totalStepsY;
    setDirectionMotorY(errY>0);

    if (abs(errY)<=100) {
      periode = 255;
    } else if (abs(errY)>3200) {
      periode = 50;
    } else {
      periode = map(abs(errY),100, 3200, 255, 50);
    }
    setSpeedMotorY(periode);

    if (errY>100 && getDY_i() || errY<-100 && getDY_s()) {
      enableMotorY();
    } else {
      disableMotorY();
    }
  }
  // Serial.println("at position!!!");
}

// &&&&&&&&&&&&&&&&&&&&&&&&&&&&&&&&&&&&&&&&&&&&&&&&
// Interrupcions
// &&&&&&&&&&&&&&&&&&&&&&&&&&&&&&&&&&&&&&&&&&&&&&&&

// Función para manejar la interrupción del Timer 1
ISR(TIMER1_COMPA_vect) {
  if (digitalRead(X_ENABLE_PIN) == LOW){
    if(dirX) {totalStepsX++;} else {totalStepsX--;}
  }
}

// Función para manejar la interrupción del Timer 2
ISR(TIMER2_COMPA_vect) {
  if (digitalRead(Y_ENABLE_PIN) == LOW){
    if(dirY) {totalStepsY++;} else {totalStepsY--;}
  }
}

// 
// Codi Principal
// 

void setup() {
  Serial.begin(9600);

  pinMode(X_STEP_PIN, OUTPUT);
  pinMode(X_DIR_PIN, OUTPUT);
  pinMode(X_ENABLE_PIN, OUTPUT);
  pinMode(Y_STEP_PIN, OUTPUT);
  pinMode(Y_DIR_PIN, OUTPUT);
  pinMode(Y_ENABLE_PIN, OUTPUT);

  pinMode(pinLED_Rojo, OUTPUT);
  pinMode(pinLED_Verde, OUTPUT);

  pinMode(pinInterruptor1, INPUT_PULLUP);
  pinMode(pinInterruptor2, INPUT_PULLUP);

  pinMode(DX_epin,INPUT_PULLUP);
  pinMode(DY_spin,INPUT_PULLUP);
  pinMode(DX_dpin,INPUT_PULLUP);
  pinMode(DY_ipin,INPUT_PULLUP);

  pinMode(A1324_1, INPUT);
  pinMode(A1324_2, INPUT);
  pinMode(A1324_3, INPUT);
  pinMode(A1324_4, INPUT);
  
  configurarTimer1(255); 
  configurarTimer2(1);
  disableMotorX();
  disableMotorY();

  totalStepsX = 0;
  totalStepsY = 0;
  // CI();
  Home();
}

void loop() {
  int estadoInterruptor1 = digitalRead(pinInterruptor1);
  int estadoInterruptor2 = digitalRead(pinInterruptor2);

  if (estadoInterruptor1 == LOW && estadoInterruptor2 == HIGH) {
    encenderRojo();
    Nivell_3();
    Home();

  } else if (estadoInterruptor1 == HIGH && estadoInterruptor2 == HIGH) {
    encenderNaranja();
    Nivell_2(); 
    Home();

  } else if (estadoInterruptor1 == HIGH && estadoInterruptor2 == LOW) {
    encenderVerde();
    Nivell_1(); 
    Home();
  }
}

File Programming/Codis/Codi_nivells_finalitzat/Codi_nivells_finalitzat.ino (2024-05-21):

// Definición de pines
const int pinLED_Rojo = 8;    // Pin para el LED rojo
const int pinLED_Verde = 9;    // Pin para el LED verde
const int pinInterruptor1 = 2; // Pin para el primer contacto del interruptor (posición 1)
const int pinInterruptor2 = 3; // Pin para el segundo contacto del interruptor (posición 3)

void setup() {
  // Configurar pines como salida
  pinMode(pinLED_Rojo, OUTPUT);
  pinMode(pinLED_Verde, OUTPUT);

  // Configurar pines de interruptor como entrada con resistencia pull-up
  pinMode(pinInterruptor1, INPUT_PULLUP);
  pinMode(pinInterruptor2, INPUT_PULLUP);

  // Inicializar comunicación serie para depuración
  Serial.begin(9600);
}

void loop() {
  // Leer el estado de los interruptores
  int estadoInterruptor1 = digitalRead(pinInterruptor1);
  int estadoInterruptor2 = digitalRead(pinInterruptor2);

  // Determinar qué color encender basado en la posición del interruptor
  if (estadoInterruptor1 == LOW && estadoInterruptor2 == HIGH) {
    Serial.println("C1");
    encenderRojo();
  } else if (estadoInterruptor1 == HIGH && estadoInterruptor2 == HIGH) {
    Serial.println("C2");
    encenderNaranja();
  } else if (estadoInterruptor1 == HIGH && estadoInterruptor2 == LOW) {
    Serial.println("C3");
    encenderVerde();
    }

  // Espera un momento antes de la siguiente lectura
  delay(500);
}

// Funciones para encender cada color
void encenderVerde() {
  digitalWrite(pinLED_Rojo, HIGH);   // Apagar LED rojo
  digitalWrite(pinLED_Verde, LOW); // Encender LED verde
}

void encenderNaranja() {
  digitalWrite(pinLED_Rojo, LOW);  // Encender LED rojo
  digitalWrite(pinLED_Verde, LOW); // Encender LED verde (combinación puede dar naranja si es un LED RGB o combinación)
}

void encenderRojo() {
  digitalWrite(pinLED_Rojo, LOW);  // Encender LED rojo
  digitalWrite(pinLED_Verde, HIGH);  // Apagar LED verde
}

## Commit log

2024-02-20 Test de com afegir un document.
2024-03-21 Codi nou de proba sensors
2024-03-26 Auto stash before merge of "main" and "origin/main"
    Some new code from Motors nema 17
2024-04-15 Carpetas ordenadas i nou codi dels motors funcionant amb timers per comparació.
2024-04-19 Nova versió del codi del motor
2024-05-07 Codi PI amb funcio de pos Home
2024-06-01 Rename Captura de pantalla 2024-03-18 a les 11.21.51.png to Motor and drivers connection
